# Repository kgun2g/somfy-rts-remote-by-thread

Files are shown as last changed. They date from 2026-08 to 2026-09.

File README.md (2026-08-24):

# Somfy RTS 우드 블라인드 컨트롤러 — ESP32 + CC1101

ESP32(C6 기본) + CC1101(447 MHz 2-FSK / 433 MHz OOK) + 0.42" OLED +
PCF8574 버튼/로터리로 **Somfy RTS** 블라인드(C6 8개 / H2 3개)를 제어하고,
**Matter-over-Thread**(SmartThings)로 노출하는 펌웨어.

한국 베네치아(Venetian) 블라인드의 **447 MHz 2-FSK 변종**을 정품 리모컨 IQ
녹음으로 역분석·검증해 송신한다(UP/DOWN/MY/PROG/TILT). 보드는 `boards/<board>.h`
핀맵·디스플레이·I2C 구성까지 보드별 교체 가능 — 브랜드-SoC 단위:
**3보드 모두 검증** — gnpe-c6(GNPE ESP32-C6-0.42)·xiao-c6(Seeed XIAO
ESP32-C6)·esp32-h2(ESP32-H2 SuperMini, I2C 공유).

레포: <https://github.com/kgun2g/somfy-rts-remote-by-thread>


&nbsp; 무료/오픈소스 — [MIT 라이선스](LICENSE).

## 주요 기능

- **Matter (보드별 구조)**: C6 = Bridge(Aggregator + 8× Bridged WindowCovering) →
  SmartThings 에 블라인드 8개 독립 타일 / H2 = composed(root 직속 3× WindowCovering,
  RAM 절약) → custom Edge driver 로 1카드 3블라인드. 둘 다 lift/tilt.
- **Somfy RTS 447 송신**: CC1101 2-FSK + RMT 비트뱅, 80비트(10바이트) 프레임,
  롤링코드, 블라인드별 주파수. Manchester 극성·HW/SW sync·byte 7~9·tilt 커맨드
  모두 정품 IQ 검증값. 한 누름 = **2 프레임**(첫 프레임 HW sync 12 + 재전송 6),
  **byte7 은 재전송 인덱스**(첫 프레임 `0x84`, 재전송 `196+rep*4`) — 정품·ESPSomfy 동일.
  > ★**rtl_433 이 보여주는 byte 값은 wire 바이트가 아니다.** 송신은 b[1..6]만
  > 체인 XOR 하지만 rtl_433 은 **b[1..9] 전체를 디스크램블**한다
  > (`표시 b8 = wire b8 ^ wire b7`, `표시 b9 = wire b9 ^ wire b8`).
  > 이걸 모르면 재전송 프레임의 byte7 을 "hold 코드" 로 오독한다 — 실제로 그렇게
  > 오독해 멀쩡하던 긴 누름을 깬 적이 있다. 자세한 건 `HANDOFF.md`.
- **OLED UI**: 동작 모션(UP/DOWN/STOP/TILT/PROG/ROT), 시계, 대상 블라인드 표시,
  설정 메뉴. **렌더러는 해상도로 자동 선택**(보드 무관, `BOARD_OLED_*`):
  **128×64 가로** / **64×128 세로** → 풀스크린 네이티브(고딕 폰트 + 7세그 시계),
  **그 외**(GNPE 72×40 등) → 72×40 논리 캔버스(어떤 패널에도 중앙 배치).
- **로터리 인코더**: detent 잠금 + 이탈 첫엣지 방향결정 + 2-연속표본
  디바운스(노이즈 내성). 클릭당 1동작(틸트 업/다운), 클릭=STOP/MY.
- **PCF8574 버튼**: UP/DOWN/SELECT/PROG/SETUP.
- **진동 wake**: JYX-1210-X160 진동 스위치(IO16). 절전/화면보호기 중 흔들면
  즉시 메인 화면 복귀.
- **설정 메뉴**: Cancel / Freq Edit / Time Set / Matter Pair / Thread Rst /
  FW Update (C6 6항목; **H2 는 Time Set·FW Update 제외 4항목**). SET 짧게=저장/실행, STOP=취소→메뉴.
- **기기별 고유 블라인드 ID + 블록 ALL**: 블라인드 주소를 ESP32 **eFuse 팩토리 MAC**
  (칩 고유·불변)에서 `F0+등차+ID` 형식으로 산출 → 여러 대를 만들어도 충돌 없음,
  OTA·factory reset 에도 불변. **4채널 = 1블록**, 블록마다 전용 ALL(채널 등차의 다음
  항)을 자동 산출 → ALL 명령 시 블록별 ALL 을 차례로 송신(채널↑ → 블록·ALL 자동↑).
  ([기기 고유 ID & 롤링코드 영속](#기기-고유-id--롤링코드-영속))
- **기기별 고유 커미셔닝 코드**: Matter 페어링 코드(discriminator/passcode)도 같은
  **eFuse MAC** 에서 산출(`efuse_commissionable.cpp`, custom CommissionableDataProvider)
  → 기기마다 다른 QR/PIN, `fctry` 플래시 없이 자동 고유. 여러 대 동시 페어링도 충돌 없음.
- **롤링코드 factory-reset 영속**: 롤링코드를 기본 NVS 와 분리된 전용
  `rollcode` 파티션에도 보존 → Matter factory reset(기본 NVS 삭제) 후에도
  모터가 "롤링코드 역행"으로 거부하지 않음.
- **3단계 화면보호기/절전**: 정상 → (유휴) 화면보호기 애니메이션(패널 ON)
  → 패널 OFF/절전. 버튼/진동/Matter/USB 로 즉시 복귀.
- **배터리 절전(2026-08-25 실측)** — 두 보드 모두 **light sleep 96 %대**:

  | | XIAO-C6 | ESP32-H2 |
  |---|---|---|
  | 잠 | **96.2 %** | **96.6 %** |
  | 깨어남 | **23.7 회/초** | **33.2 회/초** |
  | 깨우기 방식 | LP 코어 눌림 래치 + ULP 깨움 | PCF8574 `~INT` 레벨 트리거 |

  C6 는 깨어있는 시간 **13.4 % → 3.6 %**, 방전 **14.1 → 8.7 mV/시간**
  (700 mAh 로 **약 5일**). H2 는 **0.0 % → 96.6 %** — light sleep 이 한 번도 안 걸리던
  상태였다(`bt` PM 락).
  버튼 폴링을 늦췄는데도 **반응은 오히려 빨라졌다** — 실제 입력은 LP 코어(C6) 또는
  `~INT`(H2) 가 즉시 깨우고, 폴링은 안전망 역할만 한다.
  자세한 근거·측정법은 [`HANDOFF.md`](HANDOFF.md) 「절전 측정 현황」.
- **안전망**: 메인 루프 + 버튼 태스크 Task WDT 감시(hang 시 자동 리부트),
  RTC 메모리 crash breadcrumb(비정상 재부팅 시 부팅 직후 진단 로그).
- **펌웨어 업데이트(Matter OTA over Thread)**: 듀얼 OTA 파티션 + Matter OTA
  Requestor. Provider 가 `.ota` 이미지(버전↑) 배포 → 자동 다운로드/적용.
  설정 메뉴 `FW Update` 에서 버전·진행 확인. 절차: [`doc/OTA.md`](doc/OTA.md).

## SmartThings 제어 동작

| 조작 | RF 동작 |
|---|---|
| **Lift 슬라이더** | 방향 기반 — target>current=DOWN(닫힘), <=UP(열림). 모터가 그 방향대로 끝까지 주행(위치 피드백 없음). |
| **Tilt 슬라이더** | 정품 Tilt 커맨드(cmd nibble 0xB). delta 를 **7단계**로 환산해 N step burst(슬랫 각도). |
| **일시정지(Stop)** | Somfy MY 송신. 단, 직전 movement 500 ms 이내 auto-stop 은 무시. |
| **Open/Close** | Lift 먼저 송신, 동반 Tilt 는 companion 으로 skip(400 ms). |

> SmartThings WC UI 는 Lift/Tilt 슬라이더가 미러링돼 한쪽만 만져도 양쪽
> 명령이 온다 → 400 ms companion 가드로 먼저 들어온 쪽만 RF 송신(짧게만
> 움직이던 문제 해결). 두 슬라이더를 의도적으로 따로 조작하려면 400 ms 이상
> 간격을 둔다.

## 하드웨어 핀 배선

핀맵·디스플레이·I2C 구성의 단일 진실원천은 **`main/boards/<board>.h`**
(`BOARD_PIN_*` / `BOARD_OLED_*` / `BOARD_I2C_SHARED`). 다른 보드는
`boards/<board>.h` 추가 후 `-Board <name>` 으로 빌드.

### 지원 보드

| 보드 | SoC | 디스플레이 | I2C 버스 | PID | 배선문서 | 상태 |
|---|---|---|---|---|---|---|
| **GNPE ESP32-C6-0.42** | C6 | 내장 0.42″ 72×40 (180° 회전) | 분리(OLED HW + PCF 비트뱅) | `0x8000` | [gnpe-c6](doc/wiring/wiring_gnpe-c6.md) | ✅ 검증 |
| **Seeed XIAO ESP32-C6** | C6 | 외부 0.96″ 128×64 (정방향) | **LP_I2C→공유 자동폴백** | `0x8003` | [xiao-c6](doc/wiring/wiring_xiao-c6.md) | ✅ 검증 |
| **ESP32-H2 SuperMini** | H2 | 외부 모듈 | **공유**(OLED+PCF 한 HW I2C) | `0x8001` | [esp32-h2](doc/wiring/wiring_esp32-h2.md) | ✅ 검증 |

- **디스플레이 규격**은 보드별 `BOARD_OLED_*`(해상도/오프셋/회전/72×40 보정/주소).
  **렌더러는 해상도로 자동 선택**(`oled_ui.h` 의 `OLED_RENDER_*`) — 128×64 가로·64×128
  세로는 풀스크린 네이티브, 그 외는 72×40 논리 캔버스를 중앙 배치. 어느 보드든
  `BOARD_OLED_*` 만 바꾸면 OLED 교체 가능(코드 수정 불필요).
- **I2C 버스**: GNPE 는 OLED=HW I2C + PCF8574=비트뱅(서로 다른 핀). **H2 는
  `BOARD_I2C_SHARED=1` 로 OLED·PCF8574 가 HW I2C 한 버스 공유**. **XIAO 는 런타임 자동
  폴백**(`BOARD_I2C_LP_FALLBACK=1`): LP_I2C(뒷면 6/7) 우선 프로브 → 무응답 시 공유 HW
  I2C(22/23)로 전환 — 두 배선 모두 한 펌웨어로 지원.
- 아래 두 표는 **제품(보드)별** 핀 배치다. 단일 진실원천은 각 `boards/<board>.h`,
  상세 패드·실크 매핑은 [배선문서](doc/wiring/)를 따른다. 표기는 제품 실크 기준
  (GNPE `IOx` · XIAO 패드 `Dx`/뒷면 `MTxx` · H2 `GPx`), 괄호는 GPIO 번호.
  **★ = 기준(대표) 보드 — 상세 배선·이미지 기준(GNPE)**.

### 보드별 펌웨어 기능 차이

같은 펌웨어라도 보드 헤더(`boards/<board>.h`)의 매크로로 SoC·메모리·디스플레이에
맞춰 기능이 분기한다.

> **⚠️ H2 가 지금 형태로 구현된 근본 이유 = RAM 부족.** ESP32-H2 는 가용 RAM 이
> **~145 KB** 뿐이라 OpenThread **FTD** + Matter 스택만으로 free heap 이 거의 소진된다.
> 실측: Bridge(Aggregator+bridged) 구조로 블라인드 5개를 노출하면 `bad_alloc`/CHIP task
> 생성 실패, 3개여도 `somfy_app` 태스크가 free<5 KB 로 못 뜨고, BLE 커미셔닝 중에는 free 가
> **~2.5 KB** 까지 떨어져 PASE peak(20~30 KB)를 못 버틴다. 그래서 H2 펌웨어는 **기능을
> 빼서가 아니라 메모리가 허락하는 범위에 맞춰** 다음과 같이 축소·단순화한 형태로 구현됐다
> (C6 두 보드는 RAM 여유로 이런 제약이 전혀 없다):
>
> - **composed 구조**(Bridge → root 직속 WindowCovering): free 2.5 KB → **~72 KB** 회복
> - **채널 3개 / 블라인드 2개 안정 상한**: endpoint 가 늘수록 heap 압박 — 3개는 재커미셔닝(PASE peak) 때 부족할 수 있어 2개가 안전
> - **시각·OTA 기능 제거**: time 태스크·SNTP·OTA Requestor 를 빼 커미셔닝용 heap 확보 (`BOARD_DISABLE_TIME`/`BOARD_DISABLE_OTA`)
> - **CHIP PacketBuffer 풀 24 + CHIP task priority 15**: NimBLE mbuf·PacketBuffer 부족으로 PASE 가 실패하지 않도록 상향 (`CHIPProjectConfig.h`/sdkconfig)

위 메모리 대책의 결과로 **ESP32-H2** 는 아래가 C6 와 다르다(C6 두 보드는 공통):

| 항목 | GNPE / XIAO (C6) | **ESP32-H2** | 근거 매크로 |
|---|---|---|---|
| 블라인드 채널 | **8채널** (2블록·ALL2) | **3채널** (1블록·ALL1) | `BLIND_MAX_COUNT` |
| 설정 메뉴 | 6항목(Time Set·FW Update 포함) | **4항목**(Time/FW 제외) | `BOARD_DISABLE_TIME`·`BOARD_DISABLE_OTA` |
| 시각 동기/표시 | SetUTCTime + SNTP + 시계 | **없음**(메모리 절약) | `BOARD_DISABLE_TIME` |
| 펌웨어 OTA | Matter OTA over Thread | **없음**(메뉴에서 숨김) | `BOARD_DISABLE_OTA` |
| 페어링 화면 | PIN (72×40 은 PIN 만) | PIN + **QR**(128×64/64×128 패널) | 해상도 자동 |
| 동작 애니메이션 | 20fps 모션 | **동일 복구**(H2 분기 제거) | `oled_ui.c` |
| Matter 구조 | Bridge(Aggregator + Bridged EP) | **composed**(root 직속 WindowCovering) | `BOARD_MATTER_COMPOSED` |
| SmartThings 노출 | 블라인드별 독립 타일(스톡 드라이버) | **1카드 3블라인드**(custom Edge driver) | `smartthings-driver/` |

> 위 표의 모든 H2 차이는 별개 결정이 아니라 **하나의 원인(RAM 부족, 섹션 상단 박스)에서
> 파생**된 것이다 — 메모리가 더 컸다면 C6 와 동일했을 항목들. Vendor/Product 이름만은
> 메모리와 무관하게 전 보드 공통 **`NLB` / `Somfy RTS Thread`**(`CHIPProjectConfig.h`).

#### ESP32-H2 — SmartThings custom Edge driver 설치

H2 는 RAM 절약을 위해 **composed**(root 직속 WindowCovering EP1·EP2·EP3) 구조라, SmartThings
**스톡 `matter-window-covering` 드라이버는 다중 동일-타입 endpoint 를 1개만 매핑**해 블라인드가
하나만 보인다. `smartthings-driver/`(custom Edge driver)를 설치하면 **카드 1개 안에 블라인드 3개**
(component `main`/`blind2`/`blind3`)로 노출된다. (C6 두 보드는 Bridge 라 스톡 드라이버로 블라인드별
독립 타일 — **설치 불필요**. Apple/Google Home 은 H2 도 추가 작업 없이 3개가 보인다 — SmartThings 한정 보완.)

```bash
npm install -g @smartthings/cli                          # 0) CLI(Node 필요)
smartthings edge:drivers:package ./smartthings-driver    # 1) 패키지 → Driver Id 출력
smartthings edge:channels:create                         # 2) 배포 채널 생성 → Channel Id
smartthings edge:channels:assign                         # 3) 채널에 driver 할당 (인자=driverId)
smartthings edge:channels:enroll                         # 4) 내 허브를 채널에 등록 (인자=hubId)
smartthings edge:drivers:install                         # 5) 허브에 driver 설치 (인자=driverId)
```

> ⚠️ 명령마다 인자가 다르다 — `assign`=**driverId**, `enroll`=**hubId**, `install`=**driverId**.
> `channelId` 를 인자로 주면 `404 Missing driver`/`500` — **인자 없이** 실행해 대화형으로 고르는 게 안전.
> **적용**: 앱 → 블라인드 기기 → ⋮ → **Driver** → `Somfy Blinds 3-Shade (composed)` 선택(또는 삭제
> 후 재페어링 시 fingerprint VID `0xFFF1`/PID `0x8001` 로 자동 적용). 코드 수정 후 갱신이 안 먹으면
> `edge:drivers:uninstall`+`install` 또는 허브 재부팅(Edge 는 install 후 자동 갱신 최대 12h).
> 전체 절차·component 매핑·주의: [`smartthings-driver/README.md`](smartthings-driver/README.md).

### CC1101 SPI (제품별)

FSPI IO-MUX 네이티브 핀 우선(저속이라 GPIO-matrix 라우팅도 무방). 모듈 제조사마다
헤더 순서가 다르니 **모듈 실크스크린 라벨 기준**으로 배선할 것.

| CC1101 | ★ GNPE C6-0.42 | Seeed XIAO C6 | ESP32-H2 SuperMini |
|---|---|---|---|
| SCK  | IO6 | D8 (19)  | GP4  |
| MOSI | IO7 | D10 (18) | GP5  |
| MISO | IO2 | D9 (20)  | GP0  |
| CSN  | IO4 | D3 (21)  | GP1  |
| GDO0 | IO8 | D6 (16)  | GP10 |

> 공통: **VCC = 3.3 V / GND, 5 V 금지.** GDO0 = RMT 비동기 TX 데이터.

### 버튼/센서 (제품별)

| 신호 | ★ GNPE C6-0.42 | Seeed XIAO C6 | ESP32-H2 SuperMini |
|---|---|---|---|
| PCF8574 SDA | IO19 | D4 (22) ‡ | GP13 ‡ |
| PCF8574 SCL | IO18 | D5 (23) ‡ | GP14 ‡ |
| PCF8574 ~INT | IO17 | D2 (2) | GP11 |
| 진동 VIBE | IO16 | D0 (0) | GP2 |
| 충전 CHG_STAT | IO3 | D7 (17) † | GP12 † |
| OLED SDA | IO1 | D4 (22) ‡ | GP13 ‡ |
| OLED SCL | IO0 | D5 (23) ‡ | GP14 ‡ |

> - **‡ I2C 공유**: **H2 = OLED·PCF8574 가 HW I2C 한 버스 공유**(같은 핀, `BOARD_I2C_SHARED=1`).
>   **XIAO 는 LP_I2C(6/7) 미연결 시 이 공유 버스로 자동 폴백**. GNPE 는 PCF8574 소프트 비트뱅.
> - **XIAO PCF8574 = 자동 폴백**(`BOARD_I2C_LP_FALLBACK=1`): 부팅 시 LP_I2C(뒷면 MTCK=6/
>   MTDO=7) 우선 프로브 → 무응답 시 OLED 공유(D4/D5=GPIO22/23)로 전환(택1 불필요).
>   **† CHG_STAT**: GNPE = MCP73831 STAT(IO3, active-LOW) 직결. **XIAO·H2 는 충전 status 가
>   LED 전용**이라, 대신 **VBUS 분압(active-HIGH)=USB 감지 + BAT 분압 ADC=실측 %** 조합(A+B,
>   `BOARD_CHG_STAT_ACTIVE_HIGH`·`BOARD_HAS_BAT_ADC`)으로 충전중/만충 판별. ADC: XIAO=D1·H2=GP3.
>   ⚠ **현 시제품 H2·xiao 기판은 이 두 분압이 핀에서 swap 오배선**(BAT_ADC핀=VBUS · CHG_STAT핀=BAT).
>   CHG_STAT 핀(H2 GP12·xiao GPIO17)이 ADC·comparator 불가라 잔량 % 측정 불가 → `BOARD_BAT_SWAPPED=1`
>   로 **`USB`/`BAT`/`LOW` 상태** 표시(배선도 참고). 정상 배선으로 고치면 `0` → 실측 % 자동 복귀.
> - **PCF8574**(주소 0x20) 비트 매핑(모든 보드 공통): UP=P4 · DOWN=P5 · SEL=P6 ·
>   PROG=P7 · SETUP=P3 · 로터리 A/B/BTN = P0/P1/P2. **OLED** 주소 0x3C(SSD1306/1315).
> - **좌/우 버튼(선택)**: `BOARD_HAS_LR_BUTTONS=1` 로 **PCF8575**(16핀) 사용 시 **P10=LEFT·
>   P11=RIGHT** 추가(주소·배선 동일, 칩만 교체). 동작은 [설정 메뉴 §좌/우 버튼](#좌우-버튼-선택--pcf8575) 참고.
> - **로터리 디텐트 타입**: `BOARD_ROT_HALF_STEP` — 0=full-step(**EC11**) / 1=half-step(**EC05**,
>   rest@11·00). 펌웨어 디코더 자동 분기(half-step=그레이코드 LUT 누산). **XIAO=EC05 → 1**.
> - 진동 스위치 · CHG_STAT · PCF8574 ~INT 은 모두 light-sleep **wake 소스**.

## 빌드 & 플래시

`esp-idf`·`esp-matter`·SSD1306 SDK 와 프로젝트 경로는 **시스템 환경 변수**에서 읽는다
(`WORKSPACES_PATH`·`RTS_BLINDS_THREAD_PATH`·`IDF_PATH`·`ESP_MATTER_PATH`·`ESP_SSD1306_PATH`).
**최초 1회 등록**은 [`doc/SETUP_GUIDE.md` §5-1](doc/SETUP_GUIDE.md#5-1-시스템-환경-변수-설정-최초-1회) 참고.
프로젝트 **루트가 ESP-IDF 프로젝트**다. PowerShell 사용(Git Bash 는 MSYSTEM 충돌).

```powershell
./build.ps1 -Board esp32-c6 -Action build               # 빌드 (기본 보드)
./build.ps1 -Board esp32-c6 -Action flash -Port COM3    # 플래시
./build.ps1 -Board esp32-c6 -Action erase -Port COM3    # 전체 지움(페어링 삭제)
./build.ps1 -Board esp32-c6 -Action menuconfig          # Kconfig 편집
```

- `-Board` 기본값은 `esp32-c6`(생략 가능). 기본 보드는 기존 `build/` +
  `sdkconfig` 를 그대로 사용(역호환). 다른 보드는 `build-<board>/`,
  `sdkconfig.<board>` 별도 디렉토리/파일.
- 모든 build/flash 출력은 **`logs/<board>-<action>.log`** 로 자동 기록
  (deterministic 이름 → 덮어쓰기, 무한증식 방지). menuconfig 만 제외.
- 빌드 시작 시 보드 자산(`boards/<board>.h` + sdkconfig defaults 조합)이
  없으면 **어떤 파일이 빠졌는지** 명시하고 중단.

산출물: `build/somfy_blinds.bin` (≈1.7 MB, 앱 파티션 ~12% 여유).

### 새 보드 추가

1. `main/boards/<name>.h` — 모든 `BOARD_PIN_*`·`BOARD_OLED_*`(필요시 `BOARD_I2C_SHARED`) 정의(`gnpe-c6.h` 참고).
2. `main/boards/board_select.h` — `#elif defined(BOARD_<NAME>)` 분기 추가.
3. `build.ps1` 의 `$BoardMap` — idf target / sdkconfig defaults / esp-matter
   device 매핑 추가.
4. `sdkconfig.defaults.<name>` 작성(필요 시).

### ★ sdkconfig 주의

검증된 `sdkconfig` 가 **단일 진실원천**이다. `set-target` 으로
`sdkconfig.defaults` 에서 재생성하면 WindowCovering 클러스터 서버가
링크에서 빠져(`emberAfWindowCovering*Callback` undefined) 빌드가 깨진다.

- 평상시 `-Action build` 만 사용(기존 sdkconfig 유지).
- 부득이 `set-target` 시 스크립트가 `sdkconfig.verified.bak` 자동 백업 →
  복구: `./build.ps1 -Board <name> -Action restore-sdkconfig`.

플래시 후 재플래시가 안 되면(절전 시 USB-Serial 정지: 저전력 Matter
기기 정상 동작) 보드 **RESET** 또는 **BOOT+RESET**(다운로드 모드) 후 진행.

## 설정 메뉴 (OLED)

메인 화면에서 **SETUP 버튼 짧게** → 설정 메뉴 진입. 메뉴는 6항목 스크롤(**H2 는 4항목**)이며,
**UP/DOWN 버튼 또는 로터리 회전**으로 커서 이동, **SETUP 짧게**로 선택 항목 진입,
**STOP(로터리 클릭)** 으로 메인 복귀.

> 용어: **SETUP** = 설정 버튼(PCF8574 P3), **STOP** = 로터리 푸시 클릭,
> **틸트** = 로터리 좌/우 회전, **UP/DOWN** = 상/하 버튼.
>
> ⏻ **SETUP 15초 이상 길게 누름** = 화면 무관 **강제 재부팅**(기기 멈춤·응답불가 대비).

| 항목 | 기능 | 사용법 |
|---|---|---|
| **Cancel** | 메인 화면으로 복귀 | SETUP 짧게 = 메인 복귀 |
| **Freq Edit** | 선택된 블라인드의 송신 주파수 미세조정 (0.01 MHz 단위, 447.20~447.79) | UP / 틸트 = +, DOWN / 틸트 = − (커서 자리값) · **좌/우 = 디지트 커서**(0.1↔0.01 자리, PCF8575) · **SETUP = 저장** · STOP = 취소(변경 폐기)→메뉴 |
| **Time Set** | 날짜·시간 수동 설정 (SmartThings 미연동 시) | UP/DOWN **또는 좌/우(PCF8575)** = 편집 자리 이동(년·월·일·시·분) · 틸트 = 값 증감 · **SETUP = 저장**(시계+NVS) · STOP = 취소→메뉴 |
| **Matter Pair** | BLE 커미셔닝 윈도우 재오픈 (기존 fabric 유지, 추가 페어링) | 진입 시 자동 오픈, OLED 에 PIN 표시(128×64/64×128 패널은 좌측 PIN + 우측 **QR** 병기) · SETUP 짧게 = "준비(READY)" 확정 · STOP 짧게 = 메뉴 / 길게 = 메인 |
| **Thread Rst** | Thread 네트워크 자격증명 삭제 후 재페어링 (네트워크/허브 교체·연결 꼬임 복구용) | **SETUP 길게(2s) = 실행** · SETUP/STOP 짧게 = 취소→메뉴 · STOP 길게 = 메인 |
| **FW Update** | 펌웨어 업데이트 (Matter OTA over Thread) — 현재 버전·진행 상태 표시 | **SET = 업데이트 확인**(QueryImage) · STOP = 메뉴/메인. 상세: [`doc/OTA.md`](doc/OTA.md) |

> 🔹 **ESP32-H2 는 `Time Set`·`FW Update` 가 없는 4항목**(Cancel / Freq Edit / Matter
> Pair / Thread Rst) — 메모리 절약으로 시각·OTA 기능을 컴파일 단계에서 제외했다
> (`BOARD_DISABLE_TIME` / `BOARD_DISABLE_OTA`). [§보드별 펌웨어 기능 차이](#보드별-펌웨어-기능-차이) 참고.

### 좌/우 버튼 (선택 — PCF8575)

`BOARD_HAS_LR_BUTTONS=1` 일 때만 활성. **PCF8574(8핀) → PCF8575(16핀)** 로 칩만 교체하고
**P10=LEFT · P11=RIGHT** 를 추가한다(주소 0x20·~INT·I2C 배선 동일, read 2바이트). 동작:

| 화면 | LEFT | RIGHT |
|---|---|---|
| **메인** | 블라인드 선택 **이전** | 블라인드 선택 **다음** (SELECT 의 좌우 버전) |
| **Time Set** | 편집 자리 **이전** | 편집 자리 **다음** |
| **Freq Edit** | 디지트 커서 **0.1 자리** | 디지트 커서 **0.01 자리** (OLED 밑줄 표시 · UP/DOWN 이 그 자리값만큼 증감) |

> 좌/우 버튼 없으면(기본) 위 동작은 비활성이고 8핀 PCF8574 그대로 — `boards/<board>.h` 에서 택일.

### Freq Edit — 주파수 미세조정

블라인드별 송신 주파수를 0.01 MHz 단위로 조정한다. 표시·편집값은 **register
설정값**(기본 447.72)이며, 보드 크리스털 오차로 실제 on-air 는 다르다(아래
**RF / Somfy RTS 447** 섹션의 "register ≠ on-air" 설명 참고). 모터가 무응답이면
정품 주파수에 맞도록 여기서 미세조정. **SETUP 으로 저장**해야 NVS 에 반영되며,
저장한 값은 **재부팅 후에도 유지**된다(부팅 시 편집 범위 447.20~447.79 밖의 손상값만 기본으로 보정).

### Thread Rst — Thread 리셋

`Thread Rst` 는 **Thread 네트워크 연결을 초기화**하는 기능이다(전체 공장초기화인
`erase-flash` 보다 가벼움 — Thread/네트워크만 리셋). SETUP 길게 누르면:

1. `thread_prov_erase()` — Thread 중단 + 활성 dataset(네트워크키 등) 비움 +
   저장된 Thread 자격증명 영구 삭제.
2. BLE 커미셔닝 윈도우 재오픈 → OLED Thread 프로비저닝 화면(재페어링 대기).

**언제**: Thread 허브/Border Router 교체, Thread 연결이 꼬여 복구 안 될 때,
다른 SmartThings 계정/허브로 이전 시.

## SmartThings (Matter over Thread)

1. SmartThings 앱 → 기기 추가 → Matter → 디바이스 OLED 의 PIN/QR.
2. 커미셔닝 완료 후 블라인드 노출 — **C6** 8개 독립 타일 / **H2** 1카드 3블라인드(composed, custom Edge driver 필요).
3. 추가 페어링: 설정 메뉴 → `Matter Pair`(BLE 커미셔닝 윈도우 재개,
   기존 fabric 유지).
4. 시각: SmartThings 가 자동 동기(SetUTCTime). 미연동 시 설정 메뉴
   → `Time Set` 으로 수동 설정. (**H2 는 시각 기능 없음** — `BOARD_DISABLE_TIME`)

> 커미셔닝 중에는 OLED/버튼/RF 등 모든 부가 태스크가 정지한다(802.15.4/
> SRP/CASE 타이밍 보호 — 페어링 39-517 방지). 완료 후 자동 시작.

## RF / Somfy RTS 447 (한국 베네치아)

정품 리모컨1(addr 0xC91BF0) 의 12-bit IQ 녹음을 rtl_433 fork 로 150+ frame
디코드해 확정한 프로토콜:

- **주파수**: 기본 register 447.72 MHz → 크리스털 오차 보정 후 on-air
  ~447.678 MHz(정품과 ±3 kHz). 블라인드별 설정(설정 메뉴 → `Freq Edit`).

> #### ★ register 값(447.72) ≠ 실제 송출(447.678) — 왜?
>
> CC1101 은 **크리스털(nominal 26 MHz)** 을 기준으로 캐리어를 합성한다.
> 드라이버가 `FREQ레지스터 = 목표주파수 × 2^16 / 크리스털주파수` 로 값을
> 써넣으면, 칩은 그 값 × (실제 크리스털 / 2^16) 으로 출력한다.
>
> 문제는 **이 보드의 크리스털이 정확히 26.000000 MHz 가 아니라는 것**이다
> (제조 공차·부하 커패시터·온도로 ±수십 ppm). 측정 결과 이 모듈은
> 계산값보다 약 **-41.5 kHz**(≈-93 ppm) 낮게 송신한다. 그래서:
>
> ```
> register 447.72 입력 → 칩 합성 → 안테나 실제 출력 447.678
>                         (크리스털 오차가 -41.5 kHz 끌어내림)
> ```
>
> 정품 모터가 듣는 진짜 주파수는 **447.678** 이므로, 거기에 실제로 도달하려면
> register 에 **447.72**(= 447.678 + 0.042)를 넣어야 한다. 즉 별도 보정 코드가
> 아니라 **이 보정이 기본값 선택에 녹아 있는** 상태다.
>
> | 항목 | 의미 | 값 |
> |---|---|---|
> | register (코드→칩) | "이 주파수로 쏴" 지정값 = OLED·Freq Edit 표시값 | 447.72 |
> | on-air (안테나 출력) | 모터가 실제 받는 주파수 | ~447.678 |
> | 정품 리모컨 실측 | 목표 | 447.675~447.678 |
>
> **주의**: register 를 447.675 로 바꾸면 실제 출력이 ~447.633 으로 떨어져
> 모터가 무응답할 수 있다. OLED 상단에 보이는 주파수도 이 **register 값**이다.
> 다른 보드로 교체하면 크리스털 오차가 달라 이 보정 상수(기본 447.72)를
> 재측정·재설정해야 할 수 있다.
>
> **RF 모듈별 실측** (같은 447 대역이라도 모듈 크리스털 오차가 달라 register 권장값이 다름):
>
> | RF 모듈 | 보드 | register(설정·표시) | on-air(실측) |
> |---|---|---|---|
> | **E07-M1101D-SMA** | 테스트 보드 | 447.72 | 447.675 MHz |
> | **E07-400MM10S** | 제작 보드 | **447.70** | 447.673 MHz (실제 블라인드 인식 확인) |
>
> → 제작 보드(**E07-400MM10S**)는 `Freq Edit` 로 **447.70** 으로 맞춰야 정품 on-air(~447.67)에 도달한다.
> 새 모듈로 교체 시 SDR 등으로 on-air 를 실측해 register 를 재조정할 것.
- **변조**: 2-FSK(±2.6~2.8 kHz). (표준 433.42 MHz Somfy 는 OOK.)
- **프레임**: 80비트(10바이트). byte0=key, byte1=cmd|cks, byte2-3=rolling(BE),
  byte4-6=address(BE), byte7=0x84, byte8/9=cmd별 + calc80Checksum.
- **Manchester 극성**: '1'=LOW→HIGH, '0'=HIGH→LOW(표준 RTS/ESPSomfy 동일).
- **HW sync**: 첫 프레임 12 cycle / 반복 6 cycle, ON/OFF 2560 µs. SW sync
  4850 µs HIGH + 640 µs LOW. inter-frame gap 4000 µs.
- **주소(address)**: 24비트. 기기별로 eFuse MAC 에서 산출(아래 섹션). 주파수는
  블라인드별 NVS 저장, 롤링코드는 NVS + `rollcode` 파티션 이중 저장.
- **커맨드**: UP/DOWN/MY/PROG + **Tilt Up/Down**(cmd nibble 0xB, byte8 로 방향).
- 신규 블라인드 등록: 블라인드 선택 → `PROG` 송신(리모컨 페어링 절차).

> ESPSomfy-RTS fork(`${WORKSPACES_PATH}/ESPSomfy-RTS`)에도 동일한 447 분기를
> 반영(`modulation=0` 일 때 한국 wire-byte/timing 적용). 상세는 그 레포의
> `SOMFY_RTS_447.md`.

## 기기 고유 ID & 롤링코드 영속

여러 대를 만들어 같은 블라인드를 제어할 때 주소(=리모컨 ID)가 겹치면 안 되고,
펌웨어 업데이트·리셋에도 ID 가 바뀌면 안 된다.

### 기기별 고유 블라인드 주소 (eFuse MAC → 블록 ALL 체계)

블라인드 주소(=리모컨 ID)를 ESP32 의 **eFuse 팩토리 MAC**(칩 고유·불변)에서 FNV-1a
해시로 결정적 산출한다 (`blind_manager.c` `_derive_addresses`). 실제 Somfy 호환 리모컨
실측 규칙대로 **`F0 [중간:채널 등차] [하위:보드 ID]`** 24비트 형식이다:

```
esp_read_mac(mac, ESP_MAC_EFUSE_FACTORY);      // 칩 고유 6바이트 (불변)
h = FNV-1a(mac);  h ^= (블록+1)*0x9E3779B1;     // 블록별 salt → 블록마다 다른 base
mid  = (h>>8) % 0x27;                           // 중간바이트 = 등차 1번 최소항(0~0x26)
low  =  h     & 0xFF;                           // 하위바이트 = 보드 고유 ID
base = 0xF00000 | (mid<<8) | low;               // 채널1 주소
채널 i = base + i*0x2700;   ALL = base + 4*0x2700   // 중간바이트 +0x27 등차
```

**4채널 = 1 블록**(채널 4개 + 전용 ALL 1개). 채널이 늘면 블록(=ALL)이 자동 증가한다
(`BLIND_BLOCK_COUNT = ceil(채널수/4)`). ALL 명령은 **모든 블록의 ALL 을 차례로 송신**한다:

| 보드(채널) | 블록 | ALL | ALL 송신 |
|---|---|---|---|
| ESP32-H2 (3채널) | 1 | base+4×0x2700 | ALL 1회 |
| GNPE/XIAO C6 (8채널) | 2 | 블록0·블록1 각 ALL | ALL1, ALL2 |
| (가정) 9채널 | 3 | 블록0~2 각 ALL | ALL1, ALL2, ALL3 |

| 속성 | 보장 | 이유 |
|---|---|---|
| 기기 간 충돌 없음 | ✅ | 칩마다 다른 MAC → 다른 해시 → 다른 하위 ID |
| OTA 후 불변 | ✅ | eFuse 불변 |
| **factory reset(erase-flash) 후 불변** | ✅ | eFuse 는 flash 가 아님 + 매 부팅 enforce |
| ALL = 등차 다음 항 | ✅ | 실측: 채널 4개 뒤 ALL = base+4×0x2700(중간바이트 +0x27 규칙) |

> ⚠️ `esp_efuse_mac_get_default()` 는 C6 에서 EUI-64 형태(중간 `FF:FE` 패딩)를 줘
> 고유 바이트가 거의 없다 → 반드시 `ESP_MAC_EFUSE_FACTORY` 를 쓸 것.
> ※ **ALL 은 PROG 등록 절차가 없다** — 모터는 채널 주소만 PROG 로 받고 ALL 은 내부
> 인식한다. 펌웨어는 ALL 주소를 등차로 산출해 **송신만** 한다. 주소를 바꾼 기기는
> 채널마다 모터에 **PROG 재등록** 필요(새 주소 = 새 리모컨 ID).

### 롤링코드 factory-reset 영속 (채널 + 블록 ALL)

롤링코드는 매 송신마다 증가하고, 모터는 직전보다 작은 롤링코드를 replay 로
거부한다. 기본 NVS 에만 두면 Matter factory reset(기본 NVS 전체 삭제) 시
START 로 리셋 → 모터 무응답. 그래서 **전용 `rollcode` NVS 파티션**(partitions.csv,
0x3E6000/16KB)에 **채널과 블록 ALL 롤링코드를 모두** 보존하고(`rollcode_blob_t`
= `rolling[채널]` + `all_rolling[블록]`), 부팅 시 **더 큰 값을 채택**(역행 방지)한다.
특히 **ALL 은 PROG 재등록 절차가 없어** 롤링코드가 한 번 어긋나면 복구가 불가능하므로
ALL 롤링코드의 영속이 채널 못지않게 중요하다.

| 이벤트 | 롤링코드(채널 + 블록 ALL) |
|---|---|
| 일반 송신 | NVS + `rollcode` 파티션 동시 갱신 |
| OTA | 둘 다 보존 |
| **Matter factory reset**(기본 NVS 삭제) | `rollcode` 파티션 보존 → 채널·ALL 모두 복원 ✅ |
| 전체 `erase-flash` | 모두 삭제 → 재-PROG 필요(개발자 행위) |

### 기기별 고유 커미셔닝 코드 (eFuse MAC → discriminator/passcode)

Matter 페어링 코드(discriminator 12bit + passcode + Spake2p verifier)도 블라인드 주소와
같은 **eFuse 팩토리 MAC** 에서 결정적 산출한다(`efuse_commissionable.cpp`, custom
`CommissionableDataProvider`). `fctry`(factory_nvs_gen.py) 플래시 없이도 **기기마다 다른
페어링 코드**를 가져, 여러 대를 만들어 동시에 페어링해도 BLE discriminator 충돌이 없다.

```
mac = eFuse FACTORY MAC;   h = FNV-1a(mac) ^ "COMM" salt
discriminator = (h ^ h>>12 ^ h>>23) & 0xFFF   // 비트 폴딩 → short(상위 4bit)도 분산
passcode      = (h % 99999998) + 1            // 유효 PIN 보정
verifier      = Spake2pVerifier.Generate(iter=1000, salt(eFuse), passcode)  // PASE
```

| 속성 | 보장 |
|---|---|
| 기기 간 코드 충돌 없음 | ✅ eFuse 고유 — 실측 gnpe `3327`/12 · xiao `4032`/15 · h2 `2687`/10 (long·short 모두 다름) |
| fctry 플래시 불필요 | ✅ 펌웨어가 부팅 시 자동 산출 |
| DAC(인증서)는 별개 유지 | ✅ commissionable provider 만 교체(DAC provider 무관) |

> `sdkconfig`: **`CONFIG_CUSTOM_COMMISSIONABLE_DATA_PROVIDER=y`** (C6·H2 적용). 미설정 보드는
> 기존 경로(EXAMPLE 기본 `3840`/`20202021`). discriminator 12bit(4096)·short 4bit(16) 공간이라
> 수십 대 규모면 충돌 가능(생일 문제) — 그땐 `factory_nvs_gen.py` 로 fctry 고유성 부여.

## OLED 구동 방식 & 화면 정책 (2026-08-11 갱신)

### 비트뱅 I2C (`BOARD_OLED_BITBANG`, xiao-c6 = 1)

xiao-c6(h4)에서 **ESP32 하드웨어 I2C0 페리페럴이 "bus busy" 로 고착**되는 현상이 재현됐다.
라인은 idle(1/1)인데 `i2c.master: clear bus failed` / `reset hardware failed` 가 뜨고 버스를
지웠다 다시 만들어도 풀리지 않는다. 같은 순간 **순수 GPIO 비트뱅은 정상 ACK** 를 받는다.

→ OLED 전송을 비트뱅으로 옮겨 페리페럴을 통째로 우회한다.

- `_bbo_write()` : GPIO **레지스터 직접 접근**(`GPIO_OUT_W1TS/W1TC`, `GPIO_IN`). HAL 호출
  (`gpio_set_direction`)은 비용이 크고 불규칙해 400 kHz 에서 파형이 깨진다(화면에 랜덤 점).
- 핀은 `GPIO_MODE_INPUT_OUTPUT_OD` 로 **한 번만** 설정하고 이후 출력 레지스터만 토글한다.
  `OUTPUT_OD` 로 하면 입력 버퍼가 꺼져 읽기가 항상 0 이 되므로 반드시 `INPUT_OUTPUT_OD`.
- 속도 `BBO_HALF_US` (1 ≈ 400 kHz). 점/깨짐이 보이면 2~3 으로 올릴 것.
- HW I2C 버스를 **아예 만들지 않으므로**, PCF8574 를 OLED 와 공유 HW I2C 로 쓰는 보드
  (`BOARD_I2C_SHARED` 경로, 예: esp32-h2)는 이 옵션과 함께 쓰지 말 것.
- **이식성 주의**: 비트뱅 계측 전역(`g_bbo_tx_cnt` 등)은 `#if BOARD_OLED_BITBANG` **밖**에
  선언해야 한다. 가드 안에 두면 `BOARD_OLED_BITBANG=0` 보드(H2)에서 링크 에러가 난다.

### dirty-page 전송 감축

화면 전체를 매번 재전송하면 초당 약 450 건의 I2C 트랜잭션이 발생한다(전송 1건 = 고착 기회).
마지막으로 성공 전송한 페이지를 `s_shadow` 에 보관하고 **내용이 바뀐 페이지만** 보낸다.
전송 실패 시 shadow 를 갱신하지 않아 다음 주기에 자동 재시도되고, 검출 실패/재검출 시에는
무효화해 전량 재전송한다. 실측: 전송 **75 % 감축**, 페이지 **86 % 건너뜀**.

### 화면 정책 — 화면보호기 없음

- 화면보호기(중간 애니메이션)는 **코드째 삭제**됐다. 유휴 시간이 지나면 곧바로 패널 OFF.
- 꺼지는 시간은 **전원에 따라 다르다**(`main/somfy_config.h`):

  | 전원 | 매크로 | 기본값 | 이유 |
  |---|---|---|---|
  | USB | `CFG_SCREEN_OFF_USB_SEC` | **300초(5분)** | 전원이 무제한 — 작업 중 자꾸 꺼지면 불편 |
  | 배터리 | `CFG_SCREEN_OFF_SEC` | **10초** | 화면이 소비의 큰 몫 |

  보드별로 바꾸려면 `boards/<board>.h` 에서 먼저 정의하면 된다.
- 복귀: **버튼 또는 진동**. 스택이 자동 진입하는 상태(PAIRING/THREAD_PROV/CHARGING)는
  화면 유지 조건에서 제외했다 — 포함하면 유휴 타이머가 계속 리셋돼 화면이 영영 안 꺼진다.

### 채널변경 잠금 (`CFG_CH_LOCK_MS`, 기본 700 ms)

상/하 등을 **동시에** 누를 때 좌/우가 스쳐 채널이 바뀌는 것을 막는다. 아래 중 하나라도
해당하면 SELECT·좌·우를 무시한다.

1. RF 발생 버튼(상·하·정지(로터리)·PROG)이 눌려 있는 동안
2. 동작 애니메이션이 재생되는 동안 (`OLED_STATE_ACTION`)
3. 마지막 RF 버튼 눌림 후 `CFG_CH_LOCK_MS` 이내 (동시 누름의 "텀" 대응)

### I2C 직렬화 — 락은 `_bbo_write()` 한 곳에 (2026-08-11)

**모든 비트뱅 전송은 `_bbo_write()` 안에서 재귀 뮤텍스로 보호된다.** 락을 여기 한 곳에만
두면 호출 지점이 늘어도 자동으로 보호된다.

왜 이렇게 바뀌었나 — 전에는 `_fb_flush` 만 락을 잡아 아래 두 경로가 **무방비**였다.

| 무방비였던 경로 | 호출자 | 빈도 |
|---|---|---|
| `_oled_send_cmds()` ← `oled_ui_set_display_on()` | somfy_app | 화면 자동 OFF/ON **10초마다** |
| `_bbo_probe()` ← `_oled_try_detect()` | flush 의 early-return 경로(락 잡기 **전**) | 미검출 시 5초마다 |

태스크 우선순위가 **`btn_handler` 10 > `somfy_app` 4 > `oled_ui` 3** 이라 somfy_app 이
oled_ui 를 **선점**한다. 비트뱅은 CPU 가 곧 클럭이므로, 선점당한 전송은 SCL/SDA 가 중간
상태로 수백 µs 멈춰 SSD1306 상태머신이 고착된다(한 번 고착되면 저절로 안 풀리는 래치).

- **재귀 뮤텍스여야 한다.** `_fb_flush` 가 바깥 락을 쥔 채 `_bbo_write` 를 부르므로,
  일반 뮤텍스면 자기 자신을 기다려 **즉시 데드락**(화면 영구 정지)이다.
  `xSemaphoreCreateRecursiveMutex` + `xSemaphoreTakeRecursive`/`GiveRecursive` 를 쓸 것.
- 뮤텍스는 `oled_ui_init()` **맨 앞**에서 만든다. 늦게 만들면 그 사이 호출이
  `s_i2c_mutex == NULL` 을 만나 무보호로 통과한다.
- 락 획득 타임아웃(200 ms)이 나면 **그냥 전송한다**. 락은 겹침 방지용이지 전송의
  전제조건이 아니며, 화면을 영구히 멈추는 것보다 한 프레임 깨지는 편이 낫다.
  발생 횟수는 `[OLEDMON]` 의 `lockTO` 로 관찰한다(정상 = 0).

검증: `sim/tools/adc_oled_mutex_sim.py` (8시드 × 10분) — 수정 전 **6/8회 고착(최빠른 80초)**,
수정 후 손상 0 / 고착 0 / 배터리 측정 952/952.

**실기 장시간(2026-08-11, COM7)**: 콘솔 `cyc` 로 화면을 계속 갱신시킨 100 % 부하 +
ADC 5초 주기 병행으로 **4시간 45분 / 전송 257,562건 / 실패 0 / lockTO 0**,
`present` 284개 샘플 전부 1, 패닉·재부팅·워치독·버스복구 0건, free heap Δ-80 B.

### 충전률 측정 (재활성됨, 2026-08-11)

`TEMP_NO_CHARGE = 0`. 위 직렬화 수정으로 되살렸다.

- **측정 주기 5초 · 표본 8회는 그대로 둘 것.** 줄이면 `_nobat_track` 의
  "5분 창 / 반쪽당 30표본" 노이즈 상쇄 가정이 깨져 **배터리 미연결 오판**이 생긴다.
  (30초 주기면 반쪽당 5표본 → 노이즈가 판정 문턱 4 mV 에 근접한다.)
- 문제가 재발하면 `TEMP_NO_CHARGE` 를 1 로 되돌리고 `[OLEDMON]` 의 실패·`lockTO` 를 볼 것.

### 배터리 미연결 판정과 "78%" (2026-08-11)

배터리를 빼도 충전 IC(MCP73831)가 BAT+ 를 무부하로 **약 3,970 mV** 로 띄운다.
이 값은 OCV-SoC 곡선상 정확히 **78 %** 라, 예전에는 "배터리 없는데 78 %" 로 보였다.
**전압만으로는 실제 배터리 78 % 와 구분할 수 없다.**

유일한 단서는 **전압이 오르는가**다(무배터리 float = 안 오름 / 충전 중인 셀 = 오름).
`_nobat_track()` 이 5분 창의 전반·후반 평균을 비교해 판정한다.

- **첫 판정 전에는 % 를 표시하지 않는다** (`BAT_PCT_UNKNOWN` → 화면에 `--%`).
  단 **애매할 때만** 숨긴다: float 창(3940~4010 mV) **밖**이면 충전 IC 가 그 값을
  만들 수 없어 배터리 존재가 전압만으로 확정되므로 **대기 없이 즉시** % 를 보여준다.
  USB 가 없을 때(=배터리로 구동 중)도 배터리가 있는 게 자명하므로 즉시 표시한다.
- **창(5분)을 줄이면 안 된다.** 충전 상승률이 ≈9.3 mV/5분 이라 창이 짧으면
  전반/후반 평균차가 판정 문턱(4 mV)에 못 미쳐 **진짜 충전 중인 배터리를 "미연결"로
  오판**해 0 % 로 표시한다. 3분 창 = 2.8 mV 로 이미 위험하다.
- 실기 로그: `[BAT] 배터리 판정: 미연결 → 0% 표시 — 전반3970mV(n30) 후반3969mV(n30)
  상승-1mV (창O, 안오름O, USB=1)` 가 부팅 **5분 23초**에 나온다.
- 검증: `sim/tools/bat_pct_display_sim.py` (4개 시나리오 + 창 단축 위험 표)

### 배터리 % 표시 평활 (2026-08-11)

배터리 구동에서는 BLE 광고·RF 송신 순간 **실제로** 전압이 떨어진다. 5초 주기 측정이
그 순간에 걸리면 값이 크게 낮게 찍히고, OCV 곡선상 이 구간은 **1 % ≈ 10 mV** 라
100 mV 만 흔들려도 10 %p 가 움직인다(실측: 81→82→**74**→84→81 %).

`_read_bat_mv()` 의 8회 평균은 수십 µs 안에 끝나 **같은 순간을 8번 재는 것**이라
ADC 노이즈만 줄일 뿐 부하 변동은 못 거른다. 그래서 **표시 경로에만** 후처리를 넣었다:

1. **중앙값 5주기**(`_bat_smooth_mv`) — 송신 순간에 걸린 점을 통째로 버린다
2. **EMA(α=1/4)** — 남은 흔들림을 시간축으로 누른다

`_nobat_track` 에는 **원본 값**을 준다 — 그쪽은 5분 창 30표본 통계라 평활하면
"전압이 오르는가" 판정 가정이 깨진다. 측정 주기·표본 수도 그대로 둔다.

★**EMA 는 1/16 mV 단위로 누적**한다. C 의 정수 나눗셈은 0 쪽으로 절단하므로 1 mV
단위로 쓰면 차이가 1~3 mV 일 때 몫이 0 이 되어 **EMA 가 고착**된다.

검증(`sim/tools/bat_pct_smooth_sim.py`): 진폭 19→9 %p, 주기간 변동 4.09→0.38 %p,
송신 강하 이상치 미노출, 방전 추종 지연 2 %p 이내.

### 배터리 단독 부팅 (USB 없이) — 2026-08-11

**증상**: USB 를 빼고 배터리만 연결하면 부팅 화면에서 멈추고 40초~1분마다 재부팅.

**원인**: `esp_matter::console::init()` 이 CHIP shell 을 **우선순위 5** 태스크로 띄운다
(`somfy_app`=4, `oled_ui`=3 보다 높다). 이 태스크가 프롬프트를 출력하는데, 보조 콘솔이
USB-Serial-JTAG 이라 `esp_rom_usb_serial_putc` 가 줄바꿈마다
`usb_serial_device_tx_flush()` 로 **호스트를 기다린다**. USB 가 없으면 이 대기가 길어지고
prio 5 가 아래 태스크를 굶겨 부팅이 끝나지 않는다.

**수정**: **VBUS 가 실제로 있을 때만** CHIP shell 을 시작한다(`app_main.cpp`
`_usb_vbus_present()` — GPIO17 VBUS 분압). 콘솔은 개발용이고 `tx`/`sel`/`cyc`/`bd` 도
USB 전용이라 배터리 단독 동작에는 필요 없다.

> `usb_serial_jtag_is_connected()` 를 쓰지 않은 이유: SOF 패킷 기반이라 부팅 ~1초
> 시점엔 열거가 안 끝나 false 가 나올 수 있고, 그러면 **USB 개발 중에도 콘솔이 사라진다**.

**진단 방법 — `boot_diag`** (`main/boot_diag.c`): USB 를 꽂는 순간 증상이 사라져 시리얼
로그를 볼 수 없으므로, 전원이 끊겨도 남는 **NVS 부팅 단계 기록**을 만들었다(RTC RAM 은
배터리를 빼면 지워져 못 쓴다). app_main 경로와 somfy_app 경로를 **따로** 세고, 실패한
부팅은 별도 키에 **영구 보관**한다(정상 부팅이 덮어쓰지 않게).

- 콘솔 `bd` — 언제든 조회 / `bd clear` — 보관 기록 삭제
- 끄려면 `BOOT_DIAG_ENABLE 0`(부팅당 NVS 쓰기 ~17회)

### 진단 로그

- `[OLEDMON]` (60초 주기) — 가동시간 · 전송/실패 · 페이지 보냄/건너뜀 · **`lockTO`** · `present` · free heap
- `[BBFAIL]` — 비트뱅 전송 실패(20회마다 1줄)
- ★**로그 인코딩은 캡처 경로마다 다르다.** pyserial 직접 캡처 = **UTF-8**,
  빌드 로그(`logs/*.log`) = **CP949**. 틀리게 디코드하면 한글 에러가 0건으로 오독된다.
  `try utf-8 → except cp949` 로 판별할 것.
- ★**"실패 0"은 정상의 증거가 아니다.** OLED 미검출이면 flush 를 건너뛰어 전송도 에러도
  안 생긴다. **`present=1` 과 전송 카운터 증가를 함께** 봐야 한다.

### 알려진 미해결 / 임시 상태

- **진동센서 오검출** — 핀이 고정 HIGH 인데 ISR 이 계속 발생해 화면이 저절로 켜지는 사례.
  `[VIBE-stat] 진동=1 HIGH=300/300` 로 확인. HW 로는 VIBE 핀·VS1 배선 점검 필요.
- **ESP32-H2 메모리** — 블라인드 3개면 free heap 이 5 KB 미만까지 떨어진다(C6 는 171 KB).
  H2 는 `BLIND_MAX_COUNT` 를 2 이하로 둘 것.
  ※**2026-08-24 이후 사정이 크게 달라졌다.** `CONFIG_USE_BLE_ONLY_FOR_COMMISSIONING=y`
  로 등록 후 BLE 를 내리자 **free 11.3 KB → 40.5 KB (+29.2 KB)**. 여기에 2026-08-22
  태스크 통합(`time_update`·`time_persist` → 메인 루프)으로 5 KB 이상을 더 회수했다.
  ※단 벽은 **총량이 아니라 연속 블록**이다 — free 5.9 KB 가 남았는데도 최대 연속
  블록이 2,112 B 라 NOC 인증서 검증이 실패한 적이 있다(2026-08-19).
  ※대가: 이미 등록된 기기는 **BLE 광고를 하지 않는다.** 재페어링은 공장초기화 후.

## 안전 / 진단

- **Task WDT**: 메인 루프 + 버튼 태스크가 5 s 이상 멈추면 자동 panic→리부트.
- **Crash breadcrumb(RTC 메모리)**: 비정상 재부팅 시 부팅 직후 직전 tick
  카운터/타임스탬프/상태(screensaver·sleep·setup)를 ★ 로그로 덤프 →
  어느 태스크가 어디서 멈췄는지 추정.
- **화면보호기 stuck 복구**: 플래그가 false 여도 OLED state 가 SCREENSAVER 면
  버튼/진동 입력 시 강제 재해제.

시리얼 캡처(진단용):
```powershell
python read_serial.py COM3 115200 > logs/serial_latest.log
```

### 시리얼 콘솔 (진단 / 자동 테스트)

USB Serial JTAG 콘솔로 **버튼 없이** RF 송신·블라인드 선택·순환·주파수 설정·재부팅을
무인 제어한다 — PC 가 COM 포트로 기기를 직접 구동해 RF 를 쏘고 SDR(`somfy_cli`)로
캡처·분석하는 자동 루프에 쓴다(`read_serial.py` 패턴, `sim/tools/`).

| 명령 | 동작 |
|---|---|
| `tx up\|down\|updown\|myup\|mydown\|my\|prog [hold_ms]` | Somfy RF 송신(session-gate 우회 → combo 직접 지정). 실측 `tx up`=cmd2 · `tx updown`=cmd6 |
| `sel <0..N \| N=ALL>` | 블라인드 선택 (N = `BLIND_MAX_COUNT`; H2 `3`·C6 `8` = ALL) |
| `cyc <-1 \| 1>` | 블라인드 선택 순환(`_blind_cycle`) — PCF8575 LEFT/RIGHT 의 콘솔 버전 |
| `freq [idx mhz]` | 주파수 조회 / 설정(+NVS 저장, 447.20~447.79 클램프) |
| `reboot` | `esp_restart` 재부팅 |
| `bd` / `bl` / `vl` | 부팅 진단 / 배터리 방전 기록 / 진동센서 기록 (NVS) |
| **`tmr`** | **등록된 `esp_timer` 덤프** — 깨어남 출처 추적. 이 한 줄이 "깨어남의 78 %" 범인(쓰지도 않는 `iot_button` 20 ms 타이머)을 찾아냈다 |
| **`pm`** | **`esp_pm_dump_locks`** — 누가 light sleep 을 막는지 이름으로 나온다(`CONFIG_PM_PROFILING=y` 면 보유 시간 %까지) |
| `rt` | 태스크별 CPU 점유(`CONFIG_FREERTOS_GENERATE_RUN_TIME_STATS` 필요) |

### 절전 진단 — 추정하지 말고 찍을 것

절전 원인 추적에서 가설이 **세 번 연속 틀렸고**(LP 코어 정지 / PCF 지터 /
Matter 내부 타이머), `esp_timer_dump()` 한 줄이 그걸 끝냈다. 순서는 이렇게 한다:

1. **`tmr`** — 12~20 ms 같은 짧은 주기 타이머가 있으면 그게 천장이다.
   *신호*: 수면 길이가 **특정 값을 절대 안 넘으면** 그 주기의 타이머가 있다는 뜻.
2. **`pm`** — `Active=1` 로 오래 잡힌 락이 있으면 light sleep 은 시도조차 못 한다
   (`light_sleep_counts:0`). `batlog` 의 `pm=3` 은 "설정이 허용됐다"는 뜻일 뿐
   **자고 있다는 증거가 아니다.**
3. 배터리 구간은 USB 콘솔이 죽으므로 **NVS 로** 받는다 —
   `sim/tools/batlog_decode.py`(수면 길이 히스토그램·깨어남 원인·태스크별 반복),
   `sim/tools/pmdump_decode.py`(PM 락 보유자),
   `sim/tools/bat_current_estimate.py`(방전 → 실효 전류).
4. **비교는 같은 출발·도착 전압 구간으로.** OCV 기울기가 구간마다 2.3 배 다르다
   (3850~3950 = 5.0 mV/%p vs 4080~4150 = 11.7 mV/%p). 어기면 수면 전류가
   음수로 나오는 식의 헛계산이 된다.

> ⚠️ **멀티미터 직렬 전류 측정은 이 기판에서 불가**(배터리 선을 끊을 수 없다).
> 배터리 +/− 에 **전류계 모드로 직결하면 셀 단락** — 절대 금지. 전압만 잰다.

> ★ **USB Serial JTAG 를 primary 콘솔**로 둬야 명령 입력이 먹는다(UART default 면 COM 에
> stdin 이 없어 write 가 hang). 또 pyserial 로 포트를 **여러 번 여닫으면 DTR 토글로 리셋**되니
> 한 세션(단일 open) 안에서 연속 전송할 것.

## 프로젝트 구조

```
somfy-blinds-things-by-claude/        ← ESP-IDF 프로젝트 루트
├─ CMakeLists.txt   project(somfy_blinds)
├─ build.ps1        보드별 빌드/플래시/ota-image(-Board), logs/ 자동 기록
├─ sdkconfig        검증된 설정(단일 진실원천)  + sdkconfig.verified.bak
├─ sdkconfig.defaults, .c6_thread, .h2_thread, .xiao_c6
├─ partitions.csv   ota_0/ota_1(듀얼 OTA) + rollcode(롤링코드 영속) + fctry
├─ logs/            빌드/플래시/시리얼 로그(<board>-<action>.log) — git ignore
├─ dist/            보드별 Matter OTA 이미지(.ota) — git ignore
├─ main/
│   ├─ boards/             브랜드-SoC 단위 핀맵 (OTA PID 도 보드별 분리)
│   │   ├─ board_select.h   -DBOARD_<NAME> → 핀맵 분기 + 필수 매크로 검증
│   │   ├─ gnpe-c6.h        GNPE ESP32-C6-0.42 (검증, PID 0x8000)
│   │   ├─ xiao-c6.h        Seeed XIAO ESP32-C6 (검증, PID 0x8003)
│   │   ├─ esp32-c6.h       구 키 → gnpe-c6.h 별칭(역호환)
│   │   └─ esp32-h2.h       ESP32-H2 SuperMini(Thread, 검증, I2C 공유)
│   ├─ app_main.cpp        Matter 코어/노드/엔드포인트/WC delegate/OpenThread
│   ├─ app_driver.cpp      Matter attribute/identify 글루
│   ├─ matter_blinds_shim.cpp  matter_blinds_* C API (상태조회/재커미셔닝)
│   ├─ somfy_app.c         OLED/버튼/메뉴/시계/절전/안전망 애플리케이션
│   ├─ cc1101.c/.h         CC1101 드라이버 (핀은 boards/<board>.h 에서 파생)
│   ├─ somfy_rts.c/.h      Somfy RTS 447 프로토콜(프레임/타이밍/tilt step)
│   ├─ blind_manager.c/.h  블라인드 상태/NVS
│   ├─ oled_ui.c/.h        OLED UI/모션
│   ├─ button_handler.c/.h PCF8574 버튼 + 로터리 + 진동 ISR
│   ├─ thread_provision.c/.h
│   ├─ somfy_config.h      핀(BOARD_PIN_* 참조)/타임존/주파수 등 설정
│   └─ gen_build_epoch.cmake  빌드시각 헤더 생성
├─ doc/             문서(README 제외 전부) — 아래 "문서" 참고
│   ├─ SETUP_GUIDE.md   배선/빌드/플래시/페어링 단계별 가이드
│   ├─ CHECKLIST.md     기능 체크리스트 + 메모리/파티션 현황
│   ├─ OTA.md           Matter OTA(over Thread) 워크플로
│   ├─ CLEANUP_v3.5.md  정리 노트
│   ├─ architecture.html 아키텍처 다이어그램
│   ├─ wiring/          보드별 배선도 (gnpe-c6 / xiao-c6 / esp32-h2)
│   └─ CC1101/ esp32/ parts/  데이터시트·핀맵 이미지·부품 자료
└─ test/            가상/온에어/디코더 테스트 하네스(build_test.ps1)
```

## 문서

루트에는 본 `README.md` 만 두고, 나머지 문서는 모두 [`doc/`](doc/) 아래에 있다.

| 문서 | 내용 |
|---|---|
| [`doc/SETUP_GUIDE.md`](doc/SETUP_GUIDE.md) | 배선·빌드·플래시·Matter 페어링·트러블슈팅 단계별 가이드 |
| [`doc/CHECKLIST.md`](doc/CHECKLIST.md) | 구현 기능 체크리스트, 메모리/파티션 현황 |
| [`doc/OTA.md`](doc/OTA.md) | Matter OTA(over Thread) 이미지 생성·배포·보드별 PID |
| [`smartthings-driver/README.md`](smartthings-driver/README.md) | **ESP32-H2(composed) 전용** SmartThings custom Edge driver — 1카드 3블라인드 노출 + CLI 배포 절차 |
| [`doc/wiring/`](doc/wiring/) | **보드별 배선도** — [gnpe-c6](doc/wiring/wiring_gnpe-c6.md) · [xiao-c6](doc/wiring/wiring_xiao-c6.md) · [esp32-h2](doc/wiring/wiring_esp32-h2.md) |
| [`doc/architecture.html`](doc/architecture.html) | 아키텍처 다이어그램 |

> `CLAUDE.md`(루트) 는 에디터 툴 지침이라 문서가 아니며, Claude Code 가 루트에서
> 읽어야 하므로 이동하지 않는다.

## 외부 의존성 (SDK, 별도 위치 유지)

대형 SDK 는 저장소에 포함하지 않고 환경변수 경로에서 참조한다. **검증에 사용한 정확한 리비전**:

| 의존성 | 버전 / 리비전 | 경로 |
|---|---|---|
| **ESP-IDF** | **v5.4.1** (tag · 커밋 `4c2820d377`) | `${WORKSPACES_PATH}/esp-idf` |
| **esp-matter** | 커밋 `7706cfbd` (main · 2026-03-31 · 태그 없음) | `${WORKSPACES_PATH}/esp-matter` |
| **esp-idf-ssd1306** | 커밋 `554df45` (master · 2026-02-20) | `${WORKSPACES_PATH}/esp-idf-ssd1306` |

> esp-matter 는 connectedhomeip(Matter 코어)를 submodule 로 동봉 — esp-matter 리비전에 고정된다.

### 관리 컴포넌트 (IDF Component Manager · 자동 다운로드)

`main/idf_component.yml` 이 직접 선언하고 나머지는 esp-matter 가 끌어온다. 잠금은
`dependencies.lock`(매니페스트 `2.0.0` · target `esp32c6`):

| 컴포넌트 | 버전 | 용도 |
|---|---|---|
| `espressif/qrcode` | **0.2.0** | OLED 페어링 QR 인코더 (직접 선언 `*` → 잠금 0.2.0) |
| `espressif/cmake_utilities` | 1.1.1 (`^1`) | 빌드 유틸 (직접 선언) |
| ~~`espressif/button`~~ | ~~4.1.6~~ | **2026-08-24 제거** — 20 ms 주기 `esp_timer` 를 상시 돌려 깨어남의 78 %를 차지했다. 공장초기화 BOOT 버튼 하나에만 쓰였고(사용 안 함), 실제 조작 버튼은 전부 PCF8575 → `button_handler` 가 처리한다 |
| `espressif/mdns` | 1.11.1 | Matter mDNS / SRP |
| `espressif/esp_secure_cert_mgr` | 2.9.2 | DAC 인증서 파티션 |
| `espressif/esp_delta_ota` · `esp_encrypted_img` | 1.1.4 · 2.3.0 | OTA 델타 · 암호화 |

## 참조 프로젝트

본 펌웨어가 의존하거나 참조한 프로젝트와 git 주소.

| 프로젝트 | 버전 / 리비전 | 용도 | Git |
|---|---|---|---|
| **이 프로젝트** | v3.x (Matter over Thread) | Somfy RTS · Matter-over-Thread 펌웨어 | <https://github.com/kgun2g/somfy-rts-remote-by-thread> |
| **ESP-IDF** | **v5.4.1** | ESP32 빌드 SDK/RTOS (Apache-2.0) | <https://github.com/espressif/esp-idf> |
| **esp-matter** | `7706cfbd` (main) | Matter SDK (Apache-2.0) | <https://github.com/espressif/esp-matter> |
| **connectedhomeip** | esp-matter 동봉 submodule | Matter 코어 SDK (esp-matter 가 래핑, Apache-2.0) | <https://github.com/project-chip/connectedhomeip> |
| **esp-idf-ssd1306** | `554df45` (master) | SSD1306/SSD1315 OLED 컴포넌트 (MIT) | <https://github.com/nopnop2002/esp-idf-ssd1306> |
| **ESPSomfy-RTS** | fork (447 분기 · `modulation==0`) | Somfy RTS 프로토콜 참조 구현 (447 분기 작업의 기준) | <https://github.com/kgun2g/ESPSomfy-RTS> |
| **rtl_433** | fork (`somfy-RTS-447` device) | RF 디코딩·검증(송신 프레임 역검증) | <https://github.com/kgun2g/rtl_433> |

> Somfy RTS 447 분기는 본 저장소와 더불어 `ESPSomfy-RTS`·`rtl_433` 의 로컬 fork(`modulation==0`
> / `somfy-RTS-447`)에도 반영했다. 각 의존성은 자체 라이선스(대부분 Apache-2.0/MIT)를 따른다.

| 역할 | Fork (kgun2g) | Upstream |
|---|---|---|
| ESPSomfy-RTS (447 MHz 지원 추가) | https://github.com/kgun2g/ESPSomfy-RTS | https://github.com/rstrouse/ESPSomfy-RTS |
| rtl_433 (447 MHz 지원 추가) | https://github.com/kgun2g/rtl_433 | https://github.com/merbanan/rtl_433 |
| SDR# plugin (447 MHz 지원 추가, SDR# 측 UI) | https://github.com/kgun2g/plugin-Rtl433-for-SdrSharp | https://github.com/marco402/plugin-Rtl433-for-SdrSharp |
| SDR# plugin DLL (447 MHz 지원 추가) | https://github.com/kgun2g/Rtl_433_dll-for-plugin-SdrSharp | https://github.com/marco402/Rtl_433_dll-for-plugin-SdrSharp |
| GraphLibSpecific (.NET 9 재빌드) | https://github.com/kgun2g/GraphLibSpecific | https://github.com/marco402/GraphLibSpecific |

## 라이선스

[MIT 라이선스](LICENSE) — 자유롭게 사용·수정·배포 가능(무료/오픈소스). © 2026 kgun2g.
저작권 고지와 라이선스 전문을 포함하면 된다. 외부 의존성(ESP-IDF·esp-matter 등)은
각 프로젝트의 라이선스를 따른다.

## 참고

- 핀맵·빌드·버전의 현행 기준은 본 README 와 `main/boards/<board>.h` 다.
  다른 문서와 상충 시 본 문서 우선.

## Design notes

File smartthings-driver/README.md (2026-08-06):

# Somfy Blinds 3-Shade — SmartThings custom Edge driver

composed Matter 기기(root EP0 + WindowCovering EP1·EP2·EP3)를 **SmartThings 카드 1개 안에 블라인드 3개
컨트롤**(component `main` / `blind2` / `blind3`)로 노출한다. 스톡 `matter-window-covering` driver 가
composed 의 다중 동일-타입 endpoint 를 1개만 매핑하는 한계를 우회한다.

> 펌웨어는 이미 WindowCovering endpoint 3개를 정상 노출한다(Apple/Google Home 은 추가 작업 없이 3개가
> 보인다). 이 driver 는 **SmartThings 쪽 매핑**만 보완한다.

## 구조
```
smartthings-driver/
  config.yml                 # driver 메타(name, packageKey, matter 권한)
  fingerprints.yml           # VID 0xFFF1 / PID 0x8001 → profile 자동 할당
  profiles/somfy-blinds-3.yml# component 3개(main, blind2, blind3) 정의
  src/init.lua               # endpoint ↔ component 매핑 + WindowCovering 핸들러
```

## 배포 (SmartThings CLI)

> ⚠️ **인자 주의** — 명령마다 인자가 다르다:
> - `edge:channels:assign`  인자 = **driverId** (채널은 대화형/`--channel`)
> - `edge:channels:enroll`  인자 = **hubId**    (채널은 대화형/`--channel`)
> - `edge:drivers:install`  인자 = **driverId** (허브는 대화형/`--hub`)
>
> **`channelId` 를 인자로 주면 안 된다** — driverId/hubId 자리로 잘못 해석돼 `404 Missing driver`
> 또는 `500` 이 난다. 헷갈리면 **인자 없이** 실행해 대화형으로 고르는 게 가장 안전하다.

```bash
# 0) CLI 설치 (Node 필요)
npm install -g @smartthings/cli

# 1) 패키지화(빌드+업로드) — 끝에 Driver Id 가 출력된다(메모)
smartthings edge:drivers:package ./smartthings-driver

# 2) 배포 채널 생성 — Channel Id 가 출력된다
#  Channel name : somfy-rts-thread
#  Channel description : somfy-rts-thread smartthings
#  url : xxxxx.com, example.com
smartthings edge:channels:create

# 3) 채널에 driver 할당  (인자 없이 → driver 선택 → 채널 선택)
smartthings edge:channels:assign
#   (인자를 줄 거면 driverId 만: smartthings edge:channels:assign <driverId>)

# 4) 내 허브를 채널에 등록  (인자 없이 → 허브 선택 → 채널 선택)
smartthings edge:channels:enroll
#   (인자를 줄 거면 hubId 만: smartthings edge:channels:enroll <hubId>)

# 5) 허브에 driver 설치  (인자 없이 → 허브 선택 → driver 선택)
smartthings edge:drivers:install
#   (인자를 줄 거면 driverId 만: smartthings edge:drivers:install <driverId>)
```

## 기기에 driver 적용
- **이미 페어링된 기기**: SmartThings 앱 → 해당 블라인드 기기 → 점 3개(설정) → **Driver** →
  목록에서 `Somfy Blinds 3-Shade (composed)` 선택. 카드가 3-component 로 다시 그려진다.
- 또는 기기를 삭제하고 재페어링하면 fingerprint(VID/PID)로 이 profile 이 자동 적용된다.

## 동작
- `main` → 첫 WindowCovering endpoint, `blind2` → 둘째, `blind3` → 셋째 (정렬 순).
- 명령: 열기/닫기/정지(`windowShade`) + 위치 %(`windowShadeLevel.setShadeLevel`) + **틸트 %(`windowShadeTiltLevel.setShadeTiltLevel`, arg=`level`)**.
- 위치 변환: Matter `CurrentPositionLiftPercent100ths`(0=열림,10000=닫힘) ↔ ST `shadeLevel`(0=닫힘,100=열림).

## 참고/주의
- SmartThings Matter Lua 라이브러리 버전에 따라 일부 API 명칭이 다를 수 있다. 패키지화 시 오류가 나면
  메시지에 맞춰 `src/init.lua` 를 조정한다(특히 `emit_event_for_endpoint` / `set_*_to_*_fn` / command 시그니처).
- tilt(틸트)도 **포함** — profile 의 3개 component 모두 `windowShadeTiltLevel` capability 선언 +
  `src/init.lua` 에 `CurrentPositionTiltPercent100ths` 구독 / `GoToTiltPercentage` 송신 핸들러 구현
  (command arg = `level`). 펌웨어가 틸트를 7단계 step burst 로 변환한다.
- 근거: SmartThings 는 "한 기기당 driver 1개" 구조라 composed 다중 endpoint 는 커스텀 driver 로만
  3-component 노출이 가능하다(community.smartthings.com/t/composite-matter-device/283091).

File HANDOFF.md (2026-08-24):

# 인수인계 — 다음 세션에서 이어갈 것

> 새 세션을 열고 **"HANDOFF.md 읽고 이어서 작업해줘"** 라고만 하면 된다.

기준: `main` 최신 커밋 (원격 `github.com/kgun2g/somfy-rts-remote-by-thread`)
> 최근 변경 요약은 `git log` 의 커밋 메시지가 가장 상세하다.

---

## ✅ 완료 — 충전률 측정 재활성 (2026-08-11)

`TEMP_NO_CHARGE = 0`. 상세는 `ISSUE_charge_adc_breaks_oled.md` 와
README 「OLED 구동 방식 & 화면 정책」 참조. 요약만 남긴다.

**진짜 원인은 "ADC 가 인터럽트를 끈다" 가 아니라 직렬화 구멍이었다.**
락(`oled_ui_i2c_lock`)이 `_fb_flush` 만 덮어, `_oled_send_cmds`(화면 자동 OFF/ON,
10초마다)와 `_bbo_probe`(미검출 시 5초마다)가 무방비였다. 우선순위가
`btn_handler 10 > somfy_app 4 > oled_ui 3` 이라 somfy_app 이 oled_ui 를 **선점**하고,
비트뱅은 CPU 가 곧 클럭이라 선점당한 전송이 SSD1306 을 고착시켰다(래치).

**수정**: 락 범위를 `_bbo_write()` 자체로 이동 + **재귀 뮤텍스**(flush 가 바깥 락을
쥔 채 부르므로 일반 뮤텍스면 즉시 데드락) + 뮤텍스 생성을 `oled_ui_init` 맨 앞으로.
락 타임아웃 200 ms 시엔 전송을 진행하고 `[OLEDMON] lockTO` 로 계수(정상 = 0).

**측정 주기 5초·표본 8회는 그대로 둘 것** — 줄이면 `_nobat_track` 의
"5분 창 / 반쪽당 30표본" 가정이 깨져 배터리 미연결 오판이 난다.

검증: `sim/tools/adc_oled_mutex_sim.py`(8시드×10분) 수정 전 6/8회 고착(최빠른 80초)
→ 수정 후 0/8.

**★실기 장시간 검증 (2026-08-11 02:15~07:00, COM7)** — 콘솔 `cyc` 로 화면을 계속
갱신시켜 OLED 를 100% 부하로 돌리고 ADC 는 5초 주기로 병행:

| 항목 | 결과 |
|---|---|
| 가동 | **4시간 45분** (17,047초) |
| 전송 | **257,562건** (907건/분) |
| **실패** | **0** (0.000000%) |
| **lockTO** | **0** |
| present | 284개 샘플 **전부 1** (미검출 0회) |
| 패닉·재부팅·워치독·abort·스택오버플로 | **각 0건** |
| OLED 검출실패 / 버스복구 호출 | **0건 / 0건** |
| free heap | 169,152B (첫 샘플 대비 **-80B**) |
| dirty-page 감축 | 98.1% (보냄 51,503 / 건너뜀 2,672,313) |

되돌리려면 `TEMP_NO_CHARGE` 를 1 로.

---

## ✅ 완료 — 배터리 "78%" 오표시 (2026-08-11)

**증상**: 배터리를 안 꽂았는데 충전률이 78% 로 표시됨.

**원인**: 배터리를 빼도 충전 IC 가 BAT+ 를 **3,970 mV** 로 띄우는데, 이 값이 OCV 곡선상
정확히 78% 다. 전압만으론 실제 배터리 78% 와 구분 불가. 구분 단서인 "전압이 오르는가"
판정(`_nobat_track`)은 **5분 창**이 차야 나오므로, 부팅 후 **5분 23초** 동안 78% 가 보였다.
(테스트로 시리얼을 열 때마다 DTR/RTS 로 리셋돼 그 5분이 계속 리셋된 것도 겹쳤다.)

**수정**: 첫 판정 전에는 % 대신 `--%` 표시(`BAT_PCT_UNKNOWN`). 단 **애매할 때만** 숨긴다 —
float 창(3940~4010 mV) 밖이거나 USB 미연결이면 배터리 존재가 자명하므로 즉시 % 표시.

**★창(5분)을 줄이지 말 것.** 충전 상승률 ≈9.3 mV/5분 vs 문턱 4 mV →
3분 창은 2.8 mV 라 **충전 중인 배터리를 "미연결"로 오판**한다.
검증표는 `sim/tools/bat_pct_display_sim.py` 및 `sim/tools/README_oled_sim.md` 부록.

---

## ✅ 완료 — 배터리 단독 부팅 멈춤 (2026-08-11)

**증상**: USB 를 빼고 배터리만 연결하면 부팅 화면에서 멈추고 40초~1분마다 재부팅.
USB 를 꽂으면 정상 — 그래서 시리얼 로그를 볼 수 없었다.

**원인**: `esp_matter::console::init()` 이 CHIP shell 을 **우선순위 5** 태스크로 띄운다
(`somfy_app`=4, `oled_ui`=3 보다 높다). 프롬프트 출력이 `esp_rom_usb_serial_putc` →
`usb_serial_device_tx_flush()` 로 **USB 호스트를 기다리는데**, 호스트가 없으면 이 대기가
길어져 prio 5 가 아래 태스크를 전부 굶긴다.

**수정**: **VBUS(GPIO17)가 있을 때만** CHIP shell 을 시작(`app_main.cpp`
`_usb_vbus_present()`). 콘솔은 개발용이고 `tx`/`sel`/`cyc`/`bd` 도 USB 전용이다.
(`usb_serial_jtag_is_connected()` 는 SOF 기반이라 부팅 1초 시점에 false 가 나올 수 있어
USB 개발 중에도 콘솔이 사라진다 — 그래서 VBUS 핀을 쓴다.)

**진단 도구 — `boot_diag`** (`main/boot_diag.c`, 이번에 새로 만듦):
전원이 끊겨도 남는 **NVS 부팅 단계 기록**. RTC RAM 은 배터리를 빼면 지워져 못 쓴다.
- app_main 경로(`stage`)와 somfy_app 경로(`stage2`)를 **따로** 센다 — 두 태스크가 동시
  진행하므로 단일 카운터로는 어느 쪽이 멈췄는지 구분 불가
- 실패한 부팅은 별도 키(`fail`)에 **영구 보관** — 정상 부팅이 덮어쓰면 증거가 날아간다
  (실제로 한 번 날렸다)
- 콘솔 **`bd`** 로 언제든 조회, `bd clear` 로 삭제
- 끄려면 `BOOT_DIAG_ENABLE 0` (부팅당 NVS 쓰기 ~17회)

**탈락시킨 가설들**: 전원/브라운아웃(배터리 4.02 V, 최저치 동일 — 사그 0), Task WDT
(5초라 주기 불일치), BAT_ADC 로직(해당 코드 미실행), I2C 스캔 NULL 핸들(`sub=10` 이라 미실행).

> ⚠ 진단 중 브라운아웃 임계값을 2.51 V → **2.92 V**(`sdkconfig.xiao-c6`
> `ESP_BROWNOUT_DET_LVL=4`)로 올렸고 **그대로 두었다**. 원인은 전원이 아니었지만,
> 더 민감한 검출은 보호 측면에서 유리하다. 되돌리려면 그 두 줄을 `SEL_7`/`7` 로.

---

## ✅ 완료 — 배터리 % 흔들림 (2026-08-11)

배터리 구동에서 81→82→**74**→84→81 % 로 튀었다. BLE 광고·RF 송신 순간 **실제로**
전압이 떨어지는데(USB 는 레일이 단단해 안 보였다), OCV 곡선상 이 구간은 1 % ≈ 10 mV 다.

표시 경로에만 **중앙값 5주기 + EMA(α=1/4)** 적용(`_bat_smooth_mv`). `_nobat_track` 에는
**원본**을 준다(5분 창 30표본 통계라 평활하면 가정이 깨짐). 측정 주기·표본 수 불변.

★**EMA 는 1/16 mV 단위로 누적**한다 — C 의 정수 나눗셈이 0 쪽으로 절단해 1 mV 단위로
쓰면 차이 1~3 mV 에서 몫이 0 이 되어 EMA 가 고착된다.
검증: `sim/tools/bat_pct_smooth_sim.py` (진폭 19→9 %p, 주기간 변동 4.09→0.38 %p).

---

## ✅ 완료 — 화면 OFF 시간 전원별 분리 (2026-08-11)

| 전원 | 매크로 | 값 |
|---|---|---|
| USB | `CFG_SCREEN_OFF_USB_SEC` | **300초(5분)** |
| 배터리 | `CFG_SCREEN_OFF_SEC` | 10초 |

---

## 남은 과제

### 1. 진동센서 — 소프트는 해결, **하드웨어 고장은 남음**

★2026-08-11 정정: "stuck 판별이 발동 안 한다"는 이전 기록은 **틀렸다**. 실기에서 발동한다.

```
W (21051) BTN: [VIBE] 센서 고장 판정(핀 고정) (최근 200샘플 HIGH=200) — 진동 무시함
```

덕분에 화면도 정상적으로 꺼진다(유휴 캡처에서 60초 이후 전송이 멈춘 채 200초 이상 유지).
→ **"화면이 저절로 켜져 안 꺼진다"는 해결됨.**

다만 근본은 하드웨어다. VIBE 핀이 **300/300 전부 HIGH 고정**이라 진동을 아예 못 읽는다.

- 현재 영향: **진동으로 화면을 깨울 수 없다**(버튼으로만 깨어남). 소프트로는 더 할 게 없다.
- 할 일: VIBE 핀(GPIO0)·VS1 진동 스위치 배선/납땜 점검. 핀이 계속 HIGH 면
  스위치 단선 또는 GND 미연결이 유력.
- 판정 로직은 `button_handler.c` 의 `VIBE_STUCK_WIN`(200샘플) — 건드릴 필요 없음.

### 2. ESP32-H2 메모리
블라인드 3개에서 **free heap 4,712B / 최대블록 2,432B**(C6 는 171KB). BLE 커미셔닝 불가.
→ H2 는 `BLIND_MAX_COUNT` 를 **2 이하**로.

### 3. COM4 하드웨어
SDA·SCL 둘 다 `0/0/0`. v4 는 PCB 풀업이 없으므로 이는 **모듈 VCC 가 0V** 라는 뜻.
→ 멀티미터로 OLED 모듈 VCC 측정. 0V 면 전원 경로(냉납·단선), 3.3V 면 모듈 손상.

### 4. OLED 장시간 고착 관찰
충전측정을 꺼도 **7시간 뒤 고착**된 이력이 있다(실패율 0.02%→12.5%).
dirty-page 감축(전송 75%↓) 이후 재발 주기가 늘었는지 `[OLEDMON]` 으로 확인.
근본 대책은 **모듈 VCC 를 GPIO+MOSFET 으로 제어**해 자동 전원 리셋(4핀 SSD1306 은 RES 핀이
없어 전원 차단만이 복구 수단).

### 5. WASM 시뮬레이터 복구 (선택)
`sim/wasm/build.ps1` 이 실제 `oled_ui.c` 를 컴파일하는데 stub 헤더가 없다
(`driver/gpio.h`, `soc/gpio_reg.h`, `soc/io_mux_reg.h`, `soc/lp_aon_reg.h`, `esp_rom_sys.h`).
이 include 들은 2026-07-17 부터 있던 것으로 **이번 변경 때문이 아니다.**
`emcc` 미설치 + 빌드 산출물 없음 → 한동안 미사용.
되살리려면 emcc 설치 → 빌드 → **컴파일러가 알려주는 에러대로** stub 추가(추측 금지).

---

## 보드 현황

| 포트 | 보드 | 옵션 | 상태 |
|---|---|---|---|
| COM7 | xiao-c6 (h4 신PCB) | `-Pcf 8575 -Rotary ec05 -Oled 128x64 -Rotate 180 -Freq 447.70` | 최신 |
| COM4 | xiao-c6 (v4 구PCB) | `-Pcf 8574` (좌/우 버튼 없음) | 커밋 `a3694d3` 시점 / OLED HW 문제 |
| COM3 | esp32-h2 | `-Pcf 8574 -Rotate 180` | 최신 / 메모리 한계 |

> ★COM3 의 **`-Rotate 180` 은 필수**다(2026-08-13 표 보완). H2 시제품은 OLED 가 180°
> 뒤집혀 장착돼 있고 `boards/esp32-h2.h` 기본값은 `BOARD_OLED_ROTATE_180 0` 이라,
> 옵션을 빼고 구우면 **화면이 상하반전**된다. `doc/wiring/wiring_esp32-h2.md:13` 에는
> 원래 적혀 있었는데 이 표에서 누락돼 실제로 한 번 당했다(2026-07-02).

빌드 예:
```bash
./build.ps1 -Board xiao-c6 -Action flash -Port COM7 -Pcf 8575 -Rotary ec05 -Oled 128x64 -Rotate 180 -Freq 447.70
```

---

## ★절전 측정 현황 (2026-08-24 갱신)

> **결론 먼저 (2026-08-25 시점, 두 보드 모두 완료)**
>
> | | C6 | H2 |
> |---|---|---|
> | 잠 | **96.2%** | **96.6%** |
> | 깨어남 | **23.7회/초** | **33.2회/초** |
> | 방전 | **8.7 mV/시간** | — |
> | free heap | 197 KB | **40.5 KB** (11.3 → +29.2) |
> | 방식 | LP 코어 눌림 래치 + ULP 깨움 | **PCF `~INT` 레벨 트리거** |
>
> C6 는 깨어있는 시간 13.4% → **3.6%**, 700mAh 로 약 5일.
> H2 는 **0.0% → 96.6%** — `bt` 락 제거(적용 누락이었다) + `~INT` ISR.

### 기여도 (C6, 배터리 유휴 실측)

| 조치 | 깨어있는 시간 | 비고 |
|---|---|---|
| 시작 | 13.4% | |
| `-Os`(그동안 IDF 기본 `-Og` 였다) | 11.9% | 회당 1.52 → 1.35ms |
| 상시 계측 끄기(PM_PROFILING·RUN_TIME_STATS) | 10.7% | 회당 1.20ms |
| 802.15.4 수면 중 전원차단 | (약 5%) | 같은 전압구간 8.37 → 8.94h |
| LP 눌림 래치 + 폴 25→100ms | 11.3% | 깨어남은 줄었으나 회당 시간이 늘어 상쇄 |
| **iot_button 20ms 타이머 제거** | **3.6%** | ★단독으로 나머지 전부보다 컸다 |

### ★★★2026-08-24 — 깨어남의 78% 는 **쓰지도 않는 예제 버튼**이었다

배터리 실측에서 **125만 회 수면 중 20ms 를 넘은 것이 한 번도 없었다.** 버튼 폴을
100ms 로 늘린 뒤에도 그대로였고, 깨어난 원인은 99.97% 가 TIMER(=예약된 알람)인데
우리 태스크 주기는 100/100/500/500ms 뿐이라 12~20ms 를 만들 게 없었다.

→ 콘솔 **`tmr`**(`esp_timer_dump`)로 찍으니 등록된 타이머가 딱 하나였다:

```
Name          Period   Times_trigg   Cb_exec_time
button_timer  20000    10743         60767 us      ← 초당 50회
```

`espressif__button`(iot_button)이 `CONFIG_BUTTON_PERIOD_TIME_MS`(20ms) 주기
esp_timer 를 **상시** 돌리고 있었다. esp-matter light 예제에서 복사돼 온 잔재로,
공장초기화(BOOT 5초 롱프레스) 하나에만 쓰였다. 실제 조작 버튼은 전부 PCF8575 →
`button_handler` 가 처리한다. 사용자 확인 후 **통째로 제거** → `tmr` 출력 타이머 0개.

> **★교훈: 추정하지 말고 찍어라.** 이 하나를 찾기까지 내가 세운 가설이 세 번 틀렸다.
> (1) 배터리 구간 LP 코어 정지 → `LP=ON` 확인으로 반증
> (2) LP 가 PCF 지터로 HP 를 깨움 → `[LPWAKE] HP 깨우기 0.00회/초` 로 반증
> (3) Matter/OpenThread 내부 타이머 → **실제로는 우리 코드**
> `esp_timer_dump()` **한 줄**이 세 번의 추정을 끝냈다.

### ★2026-08-24 — H2 는 왜 아직도 안 자나: 8/15 수정의 **적용 누락**

H2 배터리 13.9시간 실측: `sleep 0.0%`, 그런데 batlog 의 `pm` 열은 **3**
(= light sleep ON + 배터리) — **설정은 정상인데 실제로 안 잔다.**
NVS 로 받은 `esp_pm_dump_locks`:

```
Name   Type            Active  Total_count  Time(%)
bt     APB_FREQ_MAX      1          1        100%    ← 부팅부터 한 번 잡고 안 놓음
rtos0  CPU_FREQ_MAX      1       657888        6%
I2C_0  NO_LIGHT_SLEEP    0        60162        2%
Mode:  APB_MAX 94% / SLEEP 0%
light_sleep_counts:0   reject_counts:0        ← 시도조차 안 함
```

**2026-08-15 에 이미 찾아 고쳤던 그 `bt` 락이다.** 당시 조치
(`CONFIG_USE_BLE_ONLY_FOR_COMMISSIONING=y`)가 **C6 오버레이에만** 들어갔다:

```
sdkconfig.defaults.xiao_c6    ...=y     ← C6 만
sdkconfig.defaults.h2_thread  ...=n     ← H2 는 n 그대로
sdkconfig.defaults.c6_thread  ...=n
```

> **★교훈: 보드별 오버레이 구조에서 "고쳤다"는 한 보드에서만 참일 수 있다.**
> 공통 결함을 고치면 **모든 보드의 defaults 를 확인**할 것.
> (같은 성격의 사고: `g_wake_iter` 정의가 batlog 가드 안에 있어 H2 링크가 깨진 건 — 커밋 a6e5f72)

### ★★2026-08-25 — H2 는 `~INT` 를 쓸 수 있었다 (C6 결론을 일반화한 것이 오류)

`bt` 락을 푼 뒤 H2 는 깨어남이 **113.9회/초**였다(C6 는 23.7). PM 락 덤프가 이유를
보여줬다 — `I2C_0 NO_LIGHT_SLEEP` 을 **748,352회** 잡았다 놓는다. H2 는 LP 코어가
없어 버튼을 10ms 마다 HW I2C 로 직접 읽기 때문이다. C6 에서 쓴 LP 눌림 래치는
LP 코어가 전제라 H2 엔 못 쓴다.

코드 주석에는 *"`~INT` 는 이 하드웨어에서 쓸 수 없다"* 고 단정돼 있었다. 그런데
그 실측은 **C6 조건**(비트뱅 I2C, GPIO2)이었고 **H2 에서 재본 적이 없었다.**
사용자 지적으로 다시 쟀다:

```
H2  [INTOBS] 표본 16,675  LOW 18(0.1%)  ★전이 36     ← 누르면 선이 움직인다
C6  intdiag  표본 290,023 (버튼 조작 중)  전이 0회    ← 선이 죽어 있다
```

| | 이전(0.0%→) | `bt` 락 제거 | **+ `~INT` ISR** |
|---|---|---|---|
| 잠 | 0.0% | 88.8% | **96.6%** |
| 깨어남 | — | 113.9회/초 | **33.2회/초 (−71%)** |
| 회당 잠 | — | 7.8ms | **29.1ms** |

> **★내가 두 번 틀렸다.** (1) 기존 주석의 "이 하드웨어"를 그대로 믿었다.
> (2) 정지 상태에서 `~INT` 0건인 것을 "조용하다=쓸 수 있다"로 오독했다 —
> **정지 상태의 0건은 아무것도 증명하지 않는다.** 관건은 **누를 때 움직이는가**다.
> 그 오독으로 ISR 을 잘못 걸어 **인터럽트 WDT 재부팅을 44회** 냈다.

**`~INT` 를 다른 보드에서 검토할 때의 절차** (이번에 확립):

1. **ISR 없이 먼저 관찰** — 폴링이 핀 레벨을 같이 보게 해 전이를 센다(`[INTOBS]`).
   ISR 을 먼저 걸면 폭주 시 인터럽트 WDT 로 재부팅한다.
2. **버튼을 누르는 동안** 전이가 늘어나는지 볼 것. 정지 상태 0건은 무의미.
3. 살아 있으면 **레벨 트리거**로 건다. `~INT` 는 레벨 신호라 `NEGEDGE` 는 안 된다 —
   이미 LOW 면 엣지가 안 오고, read 해제 순간의 상승·재하강이 겹치면 ISR 이 몰린다.
   ISR 안에서 **즉시 자기 인터럽트를 끄고**(IRAM-safe `gpio_ll_intr_disable`),
   태스크가 포트를 읽어 **HIGH 로 돌아온 뒤에만** 재활성한다.
   등록은 **초기 read 뒤** — LOW 인 채로 등록하면 레벨 트리거가 즉시 폭주한다.
   (진동 ISR 이 X160 chatter 를 막는 방식과 동일한, 검증된 패턴)

### 측정 방법 — 반드시 지킬 것

**같은 출발 전압 · 같은 도착 전압으로 비교한다.** OCV 곡선 기울기가 구간마다
**2.3배** 다르기 때문이다(3850~3950 = 5.0mV/%p, 4080~4150 = 11.7mV/%p).
실제로 이걸 어겨 duty 가 다른 두 세션을 연립했다가 **수면 전류 −9.8mA** 라는
불가능한 값이 나온 적이 있다 — 차이는 duty 가 아니라 측정 구간이었다.

도구: `sim/tools/bat_current_estimate.py`(방전→실효 전류 역산),
`sim/tools/batlog_decode.py`(수면 길이 히스토그램·깨어남 원인·태스크별 반복),
`sim/tools/pmdump_decode.py`(PM 락 보유자).

※멀티미터 직렬 전류 측정은 **불가**(이 기판은 배터리 선을 끊을 수 없다).
  배터리 +/− 에 전류계 모드로 직결하면 **셀 단락** — 절대 금지. 전압만 잰다.

---

## 절전 측정 현황 (2026-08-14, 이력)

**비교는 반드시 "동일 전압 구간의 기울기"로 한다.** % 는 1%p 양자화 + OCV 곡선
비선형이고, 저 SoC 에서는 부하 강하가 커져 전체 평균 % 로 비교하면 왜곡된다.
세션 조건(`radio` / `screen` / `pm`)이 같은지도 같이 확인할 것 — 배터리 기록의
각 행에 들어 있다(`bl` 콘솔 명령).

| 세션 | 구성 | 길이 | 3790~4000mV 구간 | 환산 |
|---|---|---|---|---|
| #22 | 개선 전 (tick **100Hz**, LP 없음) | 6.64h | −0.67 mV/분 | **47.4mA** |
| #32 | ①tick **1000Hz** + ③LP 코어 | 7.70h | −0.75 mV/분 | **52.7mA** |

세부 4구간 중 3개 악화 + 1개 동일, 개선된 구간 **없음**. 두 세션 모두
`radio=1 / screen=OFF / pm=3` 로 조건 동일(#22 는 화면 ON 11% 포함 = 오히려 불리).

⇒ **①(tick 1000Hz)은 절전이 아니라 소폭 악화.** 2026-08-14 **100Hz 로 되돌렸다.**

> ★되돌리기 전에 반드시 했어야 하는 일: `pdMS_TO_TICKS` 는 정수 내림이라
> 100Hz 에서 **10ms 미만 대기가 0 tick = 소멸**한다. `vTaskDelay(0)` 은 yield 라
> 대기가 통째로 사라진다. 해당 4곳을 `esp_rom_delay_us()` 로 교체 완료:
> `somfy_rts.c:339/415`(5ms VCO/PA settle — SDR 실측으로 넣은 것),
> `cc1101.c:365`(2ms SCAL), `somfy_app.c:3399`(3ms CHG_STAT 풀업 안정).
> **tick 을 다시 건드릴 때는 `vTaskDelay(pdMS_TO_TICKS(x))` 전수 재검사할 것.**

100Hz 실기 확인: 부팅 정상, `tx up 3000` = 3.29초/23프레임(1000Hz 는 3.44초/24).
프레임이 오히려 촘촘해진다(1000Hz 는 프레임당 +4.81ms 여분 틈이 생겼다).

### ★★★진짜 원인 발견 (2026-08-15) — light sleep 은 한 번도 진입한 적이 없었다

`CONFIG_PM_PROFILING=y` + 콘솔 `pm`(`esp_pm_dump_locks`)으로 **계측**했다:

```
Lock stats                     Active  Total_count  Time(%)
  bt        APB_FREQ_MAX          1        1          100%   ★
  rmt_0_0   CPU_FREQ_MAX          1        1          100%   ★
  ot_sleep  APB_FREQ_MAX          0       59            1%
Mode stats:  CPU_MAX 160M  99%      ← light sleep 항목 자체가 없음
```

락 두 개가 부팅부터 100% 잡혀 있어 **automatic light sleep 이 진입 자체를 못 했다.**
①(tick)·③(LP 코어)이 3회 측정에서 전부 눈금에 안 잡힌 이유가 이것이다 —
CPU 가 CPU_MAX 에서 내려온 적이 없으니 **CPU 쪽 조치는 효과가 있을 수 없었다.**

| 조치 | 내용 | 결과 |
|---|---|---|
| `rmt_0_0` | `rmt_enable()` 이 CPU_FREQ_MAX 락을 잡는다. 부팅 때 켜고 계속 뒀다 → **burst 동안만** 켜도록(`_rmt_acquire`/`_rmt_release`, 경계는 `cc1101_enter_tx_mode`…`cc1101_idle`). `rmt_disable` 은 진행 중 전송을 자르므로 `rmt_tx_wait_all_done()` 로 먼저 비운다 | **CPU_MAX 99% → 5%** |
| `bt` | `CONFIG_USE_BLE_ONLY_FOR_COMMISSIONING` 이 CHIP 기본값 y 인데 우리는 꺼져 있었다(esp-matter 예제 기본값이 이유 없이 따라옴). 켜면 등록 후 BLE deinit + 이미 provisioned 면 부팅 시 초기화조차 안 함 | **`bt` 락 소멸, 힙 164→184KB** |

수정 후: `APB_MIN 90% / APB_MAX 3% / CPU_MAX 6%`, 락 목록 깨끗.
※USB 에서는 설계상 light sleep 을 끄므로(USB-JTAG 보호) **진입 여부는 배터리에서만** 보인다.

### ★계측을 NVS 로 남긴다 (2026-08-15)

이 보드는 **포트를 여는 순간 리셋**된다(`리셋사유=USB리셋(플래시/포트열기)`).
그래서 `esp_pm_dump_locks` 의 RAM 통계는 **읽으러 가는 행위가 지워버린다** —
실제로 배터리 구간 통계를 그렇게 날렸다.
→ `CONFIG_PM_LIGHT_SLEEP_CALLBACKS=y` + `esp_pm_light_sleep_register_cbs` 의 exit
콜백이 주는 **실제 `sleep_time_us`** 를 누적해 배터리 로그 행(`bat_sample_t.ls`)에
싣는다. `bl` 한 번으로 방전 기울기와 sleep% 를 같은 표에서 본다.

```
BL   12  + 1436s  3869mV   62%  avg  70mA  radio=1 screen=0 pm=3  sleep 87%  산포  2( 3mV)  주기
                                                                  ^^^^^^^^^
```

### 남은 후보 (기대값 순)

| 순서 | 조치 | 상태 (2026-08-24 갱신) |
|---|---|---|
| 0 | 락 해제 후 방전 측정 | **완료 (C6)** — 96.2% 수면, 8.7mV/h |
| 1 | 라디오 MAC/BB 전원차단 | **완료** — 단 `ESP_PHY_MAC_BB_PD` 가 아니라 **`IEEE802154_SLEEP_ENABLE`** 이다(전자는 Wi-Fi/BLE 용이고 RAM 2~4KB 더 먹는다). 실측 약 5% |
| 2 | CC1101 `SPWD` (송신 안 할 때 절전) | **미시도** (데이터시트 ~1.7mA 추정) |
| 3 | btn_task 유휴 주기 25ms → 100ms | **완료** — 단 주기만 늘리면 "너무 느리다"로 되돌아온다(8/20 실패). LP 눌림 래치 + LP→**태스크** 즉시 깨움이 전제. 결과적으로 반응은 25ms → **3~5ms 로 오히려 빨라짐** |
| 4 | 메인 루프·hold_repeat 깨움 | **미시도** — 합쳐 12회/초. 지금 전체가 23.7회/초라 비중이 커졌다 |
| 5 | H2 `bt` 락 제거 | **완료** — `h2_thread`·`c6_thread` 를 `y` 로(gnpe-c6 도 함께 구제). H2 0.0 → 88.8 %, free +29.2 KB |
| 6 | H2 `I2C_0` NO_LIGHT_SLEEP 락 | **완료** — PCF `~INT` 레벨 트리거로 유휴 폴 10 → 50 ms. H2 113.9 → **33.2 회/초, 96.6 %** |
| 7 | C6 메인 루프(10 회/초) + hold_repeat(2 회/초) | **미시도** — 전체가 23.7 회/초라 이제 **비중 절반**이다. 다음 지렛대 |
| 8 | H2 `~INT` 를 C6 에도? | **불가** — C6 는 `intdiag` 실측상 전이 0회(죽은 선). LP 코어 래치가 그 역할을 한다 |

### 현재 남은 병목 (2026-08-25)

두 보드 모두 96 %대에 도달해 **더 줄일 여지가 크지 않다.** 남은 것은:

| 보드 | 깨어남 내역(추정) | 비고 |
|---|---|---|
| C6 23.7 회/초 | 메인 루프 10 + btn 10 + oled 2 + hold 2 | 우리 태스크가 거의 전부 |
| H2 33.2 회/초 | 유휴 폴 20 + 메인 루프 10 + 기타 | `~INT` 안전망 폴이 절반 |

메인 루프(100 ms)를 늘리는 것이 다음 후보지만, **회당 깨어있는 시간이 늘어 상쇄될 수
있다** — C6 에서 btn 폴을 25 → 100 ms 로 늘렸을 때 깨어남은 −28 % 였는데 깨어있는
시간은 오히려 늘었다(1.15 → 1.77 ms). 반드시 **깨어남 횟수가 아니라 깨어있는 시간**
으로 판정할 것.

### LP 눌림 래치를 쓸 때 반드시 함께 해야 하는 것 (2026-08-23)

주기만 늘리면 **지연이 그대로 체감된다**(8/20 100ms 시도 → "너무 느리다" → 되돌림).
셋이 모두 있어야 한다:

1. **LP 눌림 래치** (`lp_core/pcf_poll.c` `press_latch`) — 폴 사이의 짧은 누름을 OR 로
   모은다. **로터리 A/B 는 제외**(회전 중 토글해 영구 눌림으로 굳는다 — 실제로 겪음),
   **2연속(4ms) 디바운스**(래치는 2ms 글리치도 전부 잡으므로 한 번 거른다).
2. **LP → 태스크 즉시 깨움** — IDF 에 LP→HP 인터럽트 API 가 **없다**
   (`ulp_lp_core_sw_intr_trigger` 는 HP→LP 방향). light sleep **복귀 콜백**에서
   `esp_sleep_get_wakeup_cause() == ESP_SLEEP_WAKEUP_ULP` 를 보고 통지하는 것이 유일한 통로.
   ★`vTaskDelay` 는 통지로 못 깨운다 — `ulTaskNotifyTake` 로 바꿔야 한다.
3. **`esp_sleep_enable_ulp_wakeup()`** — ★이게 빠지면 2번이 통째로 죽는다.
   실측: 등록 전 ULP 깨움 **0건** → 등록 후 버튼 10회에 **11건**.

> ★**light sleep 은 아직 한 번도 진입한 적이 없을 가능성이 크다.** 문턱은
> `FREERTOS_IDLE_TIME_BEFORE_SLEEP=3` tick 이고(FreeRTOS 최소값 2라 더 못 낮춘다),
> 100Hz 에서 3 tick = **30ms**. 그런데 btn_task 유휴가 25ms → `pdMS_TO_TICKS(25)`
> = 2 tick = 20ms 로 깨어난다 → 문턱을 못 넘는다.
> `pm=3` 은 "esp_pm_configure 가 light sleep 을 **허용**했다"는 뜻일 뿐
> **실제로 자고 있다는 증거가 아니다.** 라디오(~60mA)가 지배 항목이므로
> 1번(MAC_BB_PD)부터 가는 게 기대값이 크다.

## ✅ 완료 — PROG 긴 누름 무응답 (2026-08-15)

**증상**: PROG 를 2초 이상 눌러도 블라인드가 반응하지 않음(짧게는 정상, 정품은 동작).
훨씬 이전부터 있던 문제.

**원인**: `_build_frame` 이 **byte7 을 전 프레임 `0x84` 로 고정**하고 있었다.
정품(그리고 ESPSomfy)은 **재전송마다 byte7 을 올린다** — 첫 프레임 `0x84`,
재전송 `196 + rep*4` (= `0xC4, 0xC8, 0xCC, …`).

**수정**: `somfy_rts.c` 송신 루프에서 프레임마다
`frame[7] = first ? 0x84 : _encode80_byte7(196, i-1)` 로 갱신하고,
체크섬이 byte7 을 입력으로 받으므로 `frame[9]` 도 함께 재계산한다.
(조합 명령 UP+DOWN/MY± 은 byte9 가 실측 고정값이라 제외.)
**타이밍은 건드리지 않았다** — 과거 "byte7 가변 → 모터 무응답" 기록은 타이밍
표준값과 묶어서 바꾼 것이라 byte7 이 누명을 썼던 것으로 보인다.

### ★★★이 건에서 이틀 돈 이유 — rtl_433 표시값 ≠ wire 바이트

송신은 b[1..6]만 체인 XOR 하지만 **rtl_433 풀 디코더는 b[1..9] 전체를 디스크램블**한다
(`ESPSomfy-RTS/SOMFY_RTS_447.md` 에 명시돼 있다). 따라서

```
표시 b8 = wire b8 ^ wire b7        표시 b9 = wire b9 ^ wire b8
```

콘솔 `tx8` 로 raw byte8 을 스윕해 8/8 실증했다(`H4_02.json`):

| raw | 0x00 | 0x20 | 0x40 | 0x44 | 0x48 | 0x4C | 0xC4 | 0x60 |
|---|---|---|---|---|---|---|---|---|
| 표시 | 84 | A4 | C4 | C0 | CC | C8 | 40 | E4 |

> **오독 경위(반복 금지)** — 정품이 짧게 `84/A4/A8`, 길게 `C4/E4/E8` 로 보여
> "bit 0x40 = 누르고 있음(hold 코드)" 이라고 판단하고 그걸 구현했다가 **멀쩡하던
> 긴 누름까지 깼다**. 실제로는 wire b7(재전송 인덱스)이 XOR 되어 그렇게 보인 것이고
> **hold 코드는 존재하지 않는다**. 정품 81건 역산에서 75건(93%)이
> `0x84`(첫 프레임)/`0xC4`(재전송0)/`0xC8`(1)/`0xE8`(9)/`0xFC`(14) 로 설명된다.
> 나머지 6건은 `0xFD` 로 계열 밖 + byte9 불일치 = 디코드 오류.
> **표시값을 wire 값으로 착각하지 말 것.**

### 참조 구현을 먼저 볼 것

`D:\dev\workspaces\ESPSomfy-RTS` — 사용자가 447MHz 2-FSK 대응을 추가한 fork.
`SOMFY_RTS_447.md`(설계 근거) + `Somfy.cpp` 의 `encode80BitFrame` /
`encode80Byte7` / `sendFrame`. 우리 `somfy_rts.c` 와 구조가 사실상 같다.
전 항목 대조 결과 프레임 내용·프레임 수는 일치하고, 타이밍은 우리가 실측에 더 가깝다
(SYMBOL 644 vs 640, SW sync 4840 vs 4850, interFrame 3916 vs 4000).
**프로토콜 의문이 생기면 SDR 분석 전에 여기부터 볼 것.**

## ★RF 실측 데이터 — 추측하지 말고 여기서 확인할 것

| | 경로 |
|---|---|
| 정품 리모컨 SDR 캡처 | `D:\RTL_SDR\sdrsharp-x64\somfy_rts_447` |
| 분석 스크립트 + 절차 문서 | `D:\dev\workspaces\plugin-Rtl433-for-SdrSharp-master\scripts` (README.md §0, §7) |

캡처는 `1. up` / `2. down` / `3. my` / `4. prog` / `5. tilt up` / `6. tilt down` 로
버튼별 폴더, 그 아래 게인별 하위폴더(`3_42.1dB` 등). **한 wav = 버튼 한 번 누름.**

```bash
python diag_iq.py <정품.wav> <우리.wav>   # burst 위치/길이 (인자 2개 필수)
python dump_burst.py <wav>                # 펄스열 — HW/SW sync 개수
python measure_rf.py <wav>                # deviation / carrier offset / 타이밍
```
※경로에 공백이 있어 셸에서 `$(ls ...)` 로 넘기면 인자가 쪼개진다. Python 으로 돌릴 것.

> ★**캡처에는 "일부러 길게 누른 것"이 섞여 있다.** 사용자가 짧게/길게를 구분하라고
> 넣어둔 것이다. 한두 개만 보고 "이 버튼은 원래 길다"고 결론내면 틀린다 —
> 반드시 **전수 중앙값**으로 볼 것. 실제로 그 오독으로 PROG 특수처리가 들어갔었다
> (2026-08-13 제거). 전수 측정 결과 송신 길이는 **전 버튼 350~400ms 동일**이고,
> HW sync 도 prog 29/34/29 vs down 36/36/36/36 으로 **PROG 가 오히려 적다**.
> 정품 구조는 분석 README 에 "HW sync 12회(첫 프레임)/6회(재전송), 버튼 구분 없음"
> 으로 이미 적혀 있었다.

### 길게 누름 = **끊김 없는 한 덩어리** (2026-08-13 확정)

같은 캡처를 10ms 창으로 다시 본 결과(`scratchpad/hold_pattern.py`), ON 길이 분포는

```
300~399ms 765개 · 400~499 41 · 600~699 4 · 700~799 7 · 900~999 3 · 1300~1399 4
1. up  g066  910          ← 910ms 가 통째로 하나의 ON
3. my  g107  1360         ← 1360ms 도 하나
1. up  g070  340 [90] 670 ← 뗐다 다시 누른 것
```

즉 **정품은 누르고 있는 동안 조각내지 않고 계속 쏜다.** 간격이 보이는 캡처는
전부 별개 누름이다. 우리 펌웨어도 이 구조로 맞췄다(아래 함정 절 참조).

## 진단 콘솔 명령 (USB 시리얼)

| 명령 | 용도 |
|---|---|
| `bl` / `bl clear` | 배터리 방전 기록(NVS) — 전압·%·평균전류·**sleep%**·ADC 산포 |
| `pm` | `esp_pm_dump_locks` — PM 락 보유 + 절전모드 체류(진단 빌드 전용) |
| `tx <cmd> [hold_ms]` | RF 송신 (up/down/updown/myup/mydown/my/prog) |
| `tx8 <hex> [cmd] [hold]` | **raw byte8 강제 지정** 송신 — rtl_433 표시값과의 대응표 작성용 |
| `intpd` | `~INT` 풀다운 진단 — 배선단선 vs PCF측 고장 판별 |
| `intdiag` | `~INT` 선 관찰(15초, 버튼 조작 필요) |
| `vl` / `bd` | 진동센서 기록 / 부팅 진단 |

> ★시리얼 접속은 `write_timeout` 을 반드시 설정할 것. 안 그러면 write 가 hang 한다.
> 그리고 **포트를 여는 것만으로 기기가 리셋된다** — RAM 통계는 그때 날아간다.

## ★반드시 알아야 할 함정

- **`somfy_rts_abort` 는 프레임 경계(≈143ms)에서 딱 1번만 검사된다.**
  그래서 `abort=true; delay(20); abort=false;` 같은 **짧은 펄스는 그냥 놓친다** →
  끊으려던 job 이 안 죽고 `max_loops`(hold_ms 15s ⇒ 15.3초)까지 살아버리고,
  새 job 은 직렬 worker 뒤에 줄서서 **버튼 뗀 뒤에 나간다**.
  반드시 **레벨로 세워둔 채** `s_rf_tx_busy=false && 큐 빔` 을 확인하고 해제할 것.
  (`_hold_repeat_task` 의 `s_combo_pending` 상태머신이 이 방식이다.)
- **버튼 PRESS 는 같은 cmd 가 송신 중이면 새 job 을 만들면 안 된다**
  (`_send_command_press` → `_rf_same_cmd_inflight`). PRESS 가 `somfy_rts_abort=false`
  로 중단요청을 해제하므로, 연타 시 job 을 하나 더 넣으면 이전 job 이 abort 를
  못 만나 15초 폭주한다. `sim/tools/hold_gap_sim.py` 케이스 ⑦ 참조.
- **`_hold_repeat_task` 는 누름과 위상이 맞지 않는 자유주행 태스크다.**
  "500ms 주기니까 최대 500ms 지연"이 아니라, 게이트(500ms)+위상까지 겹쳐
  위상 스윕 실측 **최악 561ms 공백**이 나왔다. 주기 기반 재송신으로 연속성을
  만들려 하지 말 것 — 한 job 이 스스로 길게 쏘게 해야 한다.
- **PCF8574 `~INT`(GPIO2) 는 쓸 수 없다 — 2026-08-13 실측 확정.** 절전을 위해
  10ms 폴링을 인터럽트 기반으로 바꾸려는 시도(②)는 **이 하드웨어에서 불가능**하다.
  콘솔 `intdiag` 로 폴링을 멈춘 채 관찰한 결과:

  | 조건 | 표본 | 결과 |
  |---|---|---|
  | 정지 상태 | 38,765 | HIGH 100% / **전이 0회** |
  | **버튼 조작 중 15초** | **290,023** | HIGH 100% / **전이 0회** |
  | 폴링 동작 중 | 33,198 | HIGH 100% / 전이 0회 |

  회로도상 풀업(`R3 10k → +3V3`)은 **정상적으로 있다**(kicad/somfy_blinds_h4). 그런데
  버튼을 눌러도 선이 안 움직인다 → PCF8574 가 `~INT` 를 구동하지 못하는 상태
  (배선 미연결 또는 IC INT 출력 불량). **풀업 추가는 해결책이 아니다** — 이미 있다.
  → ② 를 다시 시도하기 전에 **반드시 `intdiag` 로 전이가 잡히는지 먼저 확인**할 것.

  **데이터시트 대조(`doc/parts/pcf8575.pdf`)로 대안 가설이 전부 배제됐다** —
  INT sink `IOL 1.6mA` vs 우리 부하 0.33mA(풀업 무관) · `tiv 4µs`(샘플링 무관) ·
  *"reading/writing **another device** does not affect the interrupt circuit"*(OLED 무관).
  게다가 *"resetting … when data on the port is **changed to the original setting**"* 이라
  **버튼을 누르고 있는 동안 INT 는 LOW 로 유지**된다(누름당 100ms+). 290,023 표본에서
  전이 0회는 "짧은 펄스를 놓쳤다" 로 설명 불가 = **선이 정말 안 움직인다.**
  고장 위치는 `intpd`(GPIO2 내부 풀다운+ADC, 풀다운 시 2508mV → 상단 풀업 ≈14k)로
  **R3 ~ U3 pad1 구간**으로 좁혀졌다 → **pad1 재납땜 먼저**. 자세한 건
  `doc/wiring/wiring_xiao-c6.md` 의 `~INT` 절.

  ★★**`intdiag` 는 LP 코어 폴링을 멈춰야 한다**(2026-08-15 수정). PCF 읽기가 INT 를
  해제하는데 LP 가 2ms 마다 읽으므로, 안 멈추면 관찰 구간이 통째로 HIGH 로 보인다.
  최초 측정(13:46, `1bbcbc5`)은 LP 도입(18:54, `f45ac86`)보다 5시간 앞서 이 문제가
  없었지만, **재검증 시에는 이 수정 없이는 무조건 "여전히 죽음" 이 나온다.**
  ※폴링과 INT 는 원리적으로 공존이 어렵다 —
  *"Interrupts that occur during the ACK clock pulse **can be lost**"*.
  ※`~INT` ISR 을 등록해두면 **초당 약 4,500회 폭주**해 prio 10 버튼 태스크를 짓밟아
    **버튼이 통째로 죽는다**(실측 540,522회/120초). 선은 조용하므로 전기 신호가 아니라
    `_vibe_isr_handler` 의 `gpio_ll_intr_disable`/`gpio_intr_enable` 반복과의 간섭으로
    본다. 이걸 "진단용이라 무해"하다고 남겨뒀다가 버튼을 두 번 죽였다.
- **진동센서(X160)는 배선이 아니라 센서 자체가 죽을 수 있다.** 2026-08-13 에 세 번
  재납땜하며 배선을 의심했는데, 증상이 `GND 고정(0/300)` → `HIGH 고정(300/300)` 으로
  바뀌기만 했다. **센서를 교체하니 즉시 정상**(평상시 LOW, 흔들 때 HIGH 1~75/273).
  → 판정은 콘솔 `vl`(NVS 진동 기록)로. `섞인 창`이 0 이면 센서가 한 번도 동작 안 한 것.
  정상 기준은 H2(COM3)와 같은 패턴이다.

- **로그 인코딩은 캡처 경로마다 다르다.** pyserial 직접 캡처 = **UTF-8**,
  빌드 로그(`logs/*.log`) = **CP949**. 틀리게 디코드하면 한글 에러가 **0건으로 오독**된다.
  → `try utf-8 → except cp949`. 이것 때문에 "에러 0, 해결됨"이라고 잘못 보고한 적 있음.
- **화면이 꺼지면 OLED 부하가 0 이라 검증이 안 된다.** 콘솔 `cyc 1` / `cyc -1` 을 2초마다
  보내면 화면 내용이 바뀌어 dirty-page 가 계속 생긴다(스트레스 스크립트로 활용).
- **부팅 ~100ms 구간 로그는 USB-JTAG 이 버린다.** 진단값은 static 에 저장해 루프에서 재출력.
- **긴 한글/기호 줄도 유실**된다. 중요 측정값은 짧은 ASCII 한 줄로(`XCONN sda=%d>%d ...`).
- **"에러 0"은 정상의 증거가 아니다.** OLED 미검출이면 flush 를 건너뛰어 에러도 안 난다.
  `present=1` 과 전송 카운터 증가를 함께 볼 것.
- **`#if BOARD_OLED_BITBANG` 밖에서 쓰는 전역은 가드 밖에 선언**할 것.
  가드 안에 두면 `BOARD_OLED_BITBANG=0` 보드(H2)에서 컴파일/링크 에러(실제로 두 번 발생).
- 빌드/플래시 후 **반드시 `error:` 카운트를 확인**할 것. 빌드 실패인데 "플래시 OK"로
  보고한 적 있음.
- **`sdkconfig.defaults.*` 를 고쳐도 안 먹는다.** `build.ps1` 은 보드별 `sdkconfig.<board>`
  를 실제 설정 파일로 쓰고, defaults 는 **최초 생성 때만** 씨앗으로 쓴다. 이미 만들어진
  뒤에는 `sdkconfig.xiao-c6` 를 직접 고쳐야 한다(실제로 한 번 헛빌드했다).
- **리셋 사유는 "그 부팅이 시작된 이유"** 지 "끝난 이유"가 아니다. 헷갈리면 오진한다.

---

## 배경 문서

- `README.md` 「OLED 구동 방식 & 화면 정책」 — 비트뱅 전환 이유, dirty-page, 화면 정책, 진단 로그
- `sim/tools/README_oled_sim.md` — 진단 시뮬레이터 6종 사용법과 한계
  (OLED I2C 3종 + 직렬화·채널잠금·배터리% 3종)
- `doc/CHECKLIST.md` — 기능 구현 현황
- `ISSUE_charge_adc_breaks_oled.md` — 배터리/충전 이슈 4건의 원인·근거·수정·검증 전문
- 커밋 메시지 — 각 변경의 증상→원인→조치가 상세히 기록돼 있다(`git log`)

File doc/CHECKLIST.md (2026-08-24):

# 구현 체크리스트 및 빌드 전 주의사항

## ✅ 구현 완료 항목

| 요구사항 | 파일 | 상태 |
|---|---|---|
| H/W: ESP32-C6 + CC1101 (보드 교체 가능) | `boards/<board>.h`, `cc1101.c` | ✅ |
| RF 447.72 MHz 2-FSK (한국 베네치아), 0.01 MHz 단위 | `somfy_rts.h`, `blind_manager.c` | ✅ |
| Somfy RTS 447 80비트 프로토콜 (RMT + Manchester) | `somfy_rts.c` | ✅ |
| SmartThings Matter 엔드포인트 (C6 8개 / H2 3개) | `app_main.cpp` + `matter_blinds_shim.cpp` | ✅ |
| NVS 블라인드 저장 (C6 8 / H2 3, `BLIND_MAX_COUNT`) | `blind_manager.c` | ✅ |
| **기기별 고유 블라인드 주소** (eFuse MAC → `F0`+등차+ID, 블록 ALL) | `blind_manager.c` `_derive_addresses()` | ✅ |
| **롤링코드 factory-reset 영속** (채널 + 블록 ALL 전용 파티션) | `blind_manager.c` `rollcode` 파티션(`rolling[]`+`all_rolling[]`) | ✅ |
| 블라인드 1개 또는 **블록별 전체(ALL)** 조작 — 채널↑→블록·ALL 자동↑ | `blind_manager_get_targets()` (`all_blocks[]`) | ✅ |
| UP/DOWN/SELECT/PROG/SETUP 버튼 | `button_handler.c` PCF8574 P3~P7 | ✅ |
| 로터리 엔코더 (PCF8574 P0/P1/P2) — full-step(EC11) / half-step(EC05) 분기 | `button_handler.c` + `BOARD_ROT_HALF_STEP`(EC05=그레이코드 LUT 누산) | ✅ |
| **좌/우 버튼 (선택, PCF8575 16핀)** — 메인=블라인드 선택±, 편집화면=자리이동/디지트 커서 | `BOARD_HAS_LR_BUTTONS` + `button_handler.c`(16비트 read) + `somfy_app.c` | ✅ |
| 로터리 클릭 = STOP/MY 커맨드 | `somfy_app.c` `BTN_EVT_ROT_*` 핸들러 | ✅ |
| 버튼 0.1초~15초 조작 범위 | `somfy_app.c` `_clamp_hold()` | ✅ |
| 주파수 0.01 MHz 미세조정 + 저장 | `somfy_app.c` Freq Edit → `blind_manager_set_freq()` | ✅ |
| SmartThings 앱 개별 루틴 설정 | Matter Window Covering Cluster | ✅ |
| Tilt 슬라이더 7단계 step burst | `app_main.cpp` WC delegate + `somfy_rts_send_steps()` | ✅ |
| Lift/Tilt 미러 companion 억제 (400ms) | `app_main.cpp` WC delegate | ✅ |
| 일시정지(Stop) → MY (auto-stop 500ms 가드) | `app_main.cpp` `HandleStopMotion()` | ✅ |
| 진동 wake (X160, IO16) | `button_handler.c` 진동 ISR + duty-cycle | ✅ |
| 보드별 핀맵 config + 빌드 (`-Board`) | `boards/`, `build.ps1` | ✅ |
| 빌드/플래시 로그 logs/ 자동 기록 | `build.ps1` Tee → `logs/<board>-<action>.log` | ✅ |
| 안전망 (Task WDT + crash breadcrumb) | `somfy_app.c`, `button_handler.c` | ✅ |
| **시리얼 진단 콘솔** (tx/sel/cyc/freq/reboot — 버튼 없이 RF 송신·선택·순환·주파수·재부팅 무인 제어) | `app_main.cpp` esp_console + `somfy_app.c` `somfy_app_console_*` | ✅ |
| OLED 일반 화면 (주파수/블라인드/버튼) | `oled_ui.c` `_render_normal()` | ✅ |
| OLED 애니메이션 20fps | `oled_ui.c` FreeRTOS 태스크 50ms | ✅ |
| 버튼 동작 중 5초 애니메이션 | `oled_ui.c` `_render_action()` | ✅ |
| ~~화면보호기~~ **삭제됨**(2026-07) — 대신 유휴 후 패널 OFF | `somfy_config.h` `CFG_SCREEN_OFF_USB_SEC`(USB 5분) / `CFG_SCREEN_OFF_SEC`(배터리 10초) | ✅ |
| 배터리 % 표시 평활 (중앙값 5주기 + EMA) — 송신 순간 전압강하 제거 | `somfy_app.c` `_bat_smooth_mv()` | ✅ |
| USB 없이 배터리 단독 부팅 — CHIP shell 콘솔을 VBUS 있을 때만 시작 | `app_main.cpp` `_usb_vbus_present()` | ✅ |
| 부팅 단계 NVS 기록(전원 끊겨도 보존) + `bd` 콘솔 조회 | `boot_diag.c` / `boot_diag.h` | ✅ |
| 버튼·**진동** 조작 시 즉시 화면 복귀 | `oled_ui_wake()` / `_exit_screensaver()` | ✅ |
| **OLED 비트뱅 I2C**(HW 페리페럴 고착 우회, GPIO 레지스터 직접 접근) | `oled_ui.c` `_bbo_write()` + `BOARD_OLED_BITBANG` | ✅ |
| **dirty-page 전송 감축**(변경된 페이지만 전송, 실측 86% 절감) | `oled_ui.c` `s_shadow`/`_page_dirty()` | ✅ |
| **채널변경 잠금**(RF 버튼·애니메이션 중 SELECT·좌·우 무시) | `somfy_app.c` `_ch_locked()` + `CFG_CH_LOCK_MS` | ✅ |
| **OLED 안정성 계측** `[OLEDMON]`(60초)·`[BBFAIL]` | `oled_ui.c` `g_bbo_tx_cnt`/`g_bbo_fail_cnt` | ✅ |
| 충전률 측정 (5초 주기·8표본) — 직렬화 구멍 수정 후 **재활성** | `somfy_app.c` `TEMP_NO_CHARGE=0` / `_read_bat_mv()` | ✅ |
| OLED 전송 직렬화 — 락을 `_bbo_write()` 로 이동 + **재귀 뮤텍스** | `oled_ui.c` `s_i2c_mutex` · `[OLEDMON] lockTO` | ✅ |
| **OLED 180° 회전 표시** (보드별) | `oled_ui.c` `_fb_flush()` + `BOARD_OLED_ROTATE_180` | ✅ |
| **보드별 디스플레이 규격** (해상도/오프셋/회전/72×40 보정) | `boards/<board>.h` `BOARD_OLED_*` (단일 진실원천) | ✅ |
| **해상도별 렌더러 자동 선택** (보드 무관) | `oled_ui.h` `OLED_RENDER_128X64`/`OLED_RENDER_64X128`/`OLED_RENDER_NATIVE` | ✅ |
| **풀스크린 네이티브 렌더러** (고딕 6×9 폰트 + 7세그 시계) | `oled_ui.c` 128×64 가로 / 64×128 세로 분기 | ✅ |
| **72×40 논리 캔버스 렌더러** (그 외 패널 중앙 배치/블록 스케일) | `oled_ui.c` `_fb_set_pixel()` 폴백 | ✅ |
| 시각 동기화 (Matter SetUTCTime + SNTP 폴백, KST-9) | `somfy_app.c`, Time Sync 클러스터 | ✅ |
| Matter 커미셔닝 (BLE+Thread) | `app_main.cpp` (Matter-over-Thread) | ✅ |
| **펌웨어 업데이트 (Matter OTA over Thread)** | `matter_blinds_shim.cpp` OTA 브리지 + FW Update 메뉴 | ✅ |
| **보드별 OTA 이미지** (브랜드별 PID) | `build.ps1 -Action ota-image` → `dist/*.ota` | ✅ |
| **브랜드별 보드 분리** (gnpe-c6/xiao-c6/esp32-h2) | `boards/<brand>-<soc>.h` | ✅ |
| **XIAO ESP32-C6 핀맵** (LP_I2C MTCK/MTDO, D11 미노출 회피, 온보드 충전) | `boards/xiao-c6.h` (Seeed 핀아웃 검증) | ✅ |
| **ESP32-H2 SuperMini 핀맵** | `boards/esp32-h2.h` (SuperMini 핀아웃 반영) | ✅ 검증 |
| **I2C 버스 공유** (OLED+PCF8574 한 HW I2C — XIAO·H2) | `BOARD_I2C_SHARED` + `button_handler.c` 분기 + `oled_ui_get_i2c_bus()` | ✅ XIAO·H2 검증 |
| **XIAO LP_I2C → 공유 HW I2C 자동 폴백** (부팅 프로브) | `BOARD_I2C_LP_FALLBACK` + `button_handler.c` `_pcf_lp_probe()`/런타임 디스패처 | ✅ 실기 검증(LP 미연결→공유 전환) |
| **ESP32-H2 메모리 최적화** (3채널 · 시각/OTA 메뉴 제외) | `BLIND_MAX_COUNT=3` + `BOARD_DISABLE_TIME`·`BOARD_DISABLE_OTA` | ✅ |
| **페어링 QR 코드** (128×64/64×128 — 좌 PIN + 우 QR 병기) | `oled_ui.c` `_draw_qr_native()` + `espressif/qrcode` | ✅ |
| **Matter Vendor/Product 이름** (`NLB` / `Somfy RTS Thread`) | `CHIPProjectConfig.h` | ✅ |
| SmartThings에서 개별 제어 | Matter 독립 엔드포인트 (C6 = 8 / **H2 = 3**) | ✅ |
| VSCode ESP-IDF v5.4.x 빌드 | `build.ps1`, `.vscode/tasks.json` | ✅ |
| **KiCad 10 4종 변형** (base/_y/_v2/_h2) — 구 _v·_h 삭제 | `kicad/` 폴더 | ✅ |
| **거버 패키지 ZIP + MANIFEST** | `kicad/gerber/` | ✅ |
| **PCB 0 ERROR DRC** | `_electrical_check.py` 0 issues | ✅ |
| 빌드 성공 (경고 없음) | `somfy_blinds.bin` ≈1.7 MB | ✅ |

### 배터리 변형 (`_v2` / `_h2`)

| 요구사항 | 파일 | 상태 |
|---|---|---|
| 851640 600 mAh LiPo (PCM 내장) + JST PH | `kicad/_add_battery.py` BAT1 | ✅ |
| MCP73831 단일 셀 충전 IC (300 mA) | `kicad/_add_battery.py` U4 | ✅ |
| SS14 Schottky 전원경로 | `kicad/_add_battery.py` D1 | ✅ |
| 1분 무입력 light sleep ~~(~750 µA)~~ | `somfy_app.c` `_enter_sleep()` | ✅ 아래 ★ (2026-08-25 실측 완료) |
| 충전/USB 감지 — GNPE: CHG_STAT(IO3 active-LOW) · XIAO/H2: VBUS 분압(active-HIGH) | `button_handler.c` `btn_handler_is_charging()` (`BOARD_CHG_STAT_ACTIVE_HIGH`) | ✅ |
| 배터리 표시: **실측 %**(BAT 분압 ADC) — H2·xiao-c6 모두 `BOARD_BAT_SWAPPED=0`. ~~구 기판의 BAT_ADC↔CHG_STAT 핀 swap(=1, `USB`/`BAT`/`LOW` 상태 표시)~~ 은 배선 개선판에서 해소됐다 | `somfy_app.c` `_read_bat_mv()` / `_bat_mv_to_pct()` | ✅ |
| 충전 중 sleep 차단 + 1분 OLED 애니메이션 | `somfy_app.c` + `oled_ui_show_charging()` | ✅ |

> ★ **`~750 µA` 는 설계 목표였고 그 값으로 실측된 적은 없다.** 다만 2026-08-25 에
> **두 보드 모두 light sleep 96%대**에 도달했다.
>
> | | XIAO-C6 | ESP32-H2 |
> |---|---|---|
> | 잠 | **96.2 %** | **96.6 %** |
> | 깨어남 | **23.7 회/초** | **33.2 회/초** |
> | 방전 | **8.7 mV/시간** (700 mAh 로 약 5일) | — |
> | 깨우기 | LP 코어 눌림 래치 + ULP 깨움 | PCF8574 `~INT` 레벨 트리거 |
>
> 여기까지 온 경로(전부 **계측**으로 찾았다):
>
> | 발견 | 조치 | 효과 |
> |---|---|---|
> | `bt`·`rmt_0_0` PM 락 100% 점유(2026-08-15, 콘솔 `pm`) | `USE_BLE_ONLY_FOR_COMMISSIONING=y` / RMT 를 burst 동안만 | light sleep 진입 자체가 가능해짐 |
> | ★그 수정이 **C6 오버레이에만** 적용됨(2026-08-24) | `h2_thread`·`c6_thread` 도 `y` | H2 **0.0 % → 88.8 %**, free +29.2 KB |
> | 20 ms `button_timer` 가 깨어남의 78 %(콘솔 `tmr`) | 쓰지도 않던 `espressif/button` 제거 | C6 깨어있는 시간 **11.3 % → 3.6 %** |
> | H2 만 113.9 회/초 — `I2C_0` 락 748,352회 | PCF `~INT` 레벨 트리거 ISR | H2 **33.2 회/초, 96.6 %** |
>
> **옛 측정(#22 47.4 mA / #32 52.7 mA)은 전부 PM 락에 갇힌 상태의 값**이므로
> 현재와 비교하지 말 것. 그때 ①(tick)·③(LP 코어)이 눈금에 안 잡힌 이유도 이것이다.
> 자세한 근거·측정법은 `HANDOFF.md` 의 「절전 측정 현황」.

### Sandwich 변형 (`_v2` / `_h2`)

| 요구사항 | 파일 | 상태 |
|---|---|---|
| 2-board 분리 (BOTTOM 메인 + TOP UI) | KiCad PCB 양면 + V-cut | ✅ |
| BTB1-4 board-to-board (10-pin × 2 pair) | `_create_v2_h2.py` BTB symbols | ✅ |
| BREAKAWAY_TAB (V-cut 함께 제조) | PCB 풋프린트 | ✅ |
| **VS1 진동 센서** (JYX-1210-X160, 1210 SMD) | `_add_vibration2.py` VS1 | ✅ |
| **진동 → IO16 GPIO 직결** (light sleep wake) | `boards/gnpe-c6.h` `BOARD_PIN_VIBE=16` | ✅ |
| **진동 wake** (IO16 HIGH-level, duty-cycle 검출) | `button_handler.c` 진동 ISR + 30폴 윈도우 | ✅ |
| **지속 진동 5초 holdoff** | `somfy_app.c` `VIBRATION_HOLD_MS=5000` | ✅ |

---

## ⚠️ 빌드 전 필수 확인사항

### 1. PCF8574 I2C 주소 확인

PCF8574의 A0/A1/A2 핀이 모두 GND에 연결되어 있어야 I2C 주소 `0x20`이 됩니다.

```
PCF8574 핀    연결
──────────    ────
A0 (Pin1)  → GND  (주소 bit0 = 0)
A1 (Pin2)  → GND  (주소 bit1 = 0)
A2 (Pin3)  → GND  (주소 bit2 = 0)
결과 I2C 주소: 0x20
```

다른 주소 필요 시 `button_handler.h`의 `PCF8574_I2C_ADDR` 수정.

### 2. I2C 버스 공유 (OLED + PCF8574)

OLED(SSD1315)와 PCF8574가 동일 I2C 버스(IO18/IO19)를 공유합니다.
`button_handler.c`의 I2C 뮤텍스(`s_i2c_mutex`)가 충돌을 방지합니다.

> `btn_handler_init()`은 반드시 `oled_ui_init()` **이후**에 호출해야 합니다.
> (I2C 버스가 OLED 초기화에서 먼저 열림)

### 3. COM 포트 확인

`build.ps1`의 기본 포트는 `COM3`입니다. 실제 포트로 변경:

```powershell
.\build.ps1 -Action flash -Port COM5   # 장치 관리자에서 확인
```

### 4. PowerShell만 사용 (Git Bash 사용 불가)

```
⚠ Git Bash에서 idf.py 실행 시 MSYSTEM=MINGW64 충돌로 빌드 실패
   반드시 PowerShell 또는 CMD에서 build.ps1 실행
```

### 5. 디스플레이 규격 / 해상도별 렌더러

디스플레이는 **보드별 `BOARD_OLED_*`** 가 단일 진실원천이고, 렌더러는 **해상도로
자동 선택**된다(`oled_ui.h` 의 `OLED_RENDER_*`):

| 해상도 | 렌더러 | 예 |
|---|---|---|
| **128×64 (가로)** | 풀스크린 네이티브 (고딕 6×9 + 7세그) | XIAO 0.96″ SSD1306 |
| **64×128 (세로)** | 풀스크린 네이티브 (세로 적층) | SH1107 계열 세로 패널 |
| **그 외** | 72×40 논리 캔버스 (중앙 배치) | GNPE 0.42″ SSD1315 |

- 프레임버퍼는 **물리 패널 크기**로 잡힌다(72×40=360 B, 128×64=1024 B …).
- GNPE SSD1315(72×40)는 SSD1306(128×64)과 해상도가 달라 **컬럼 오프셋
  `BOARD_OLED_COL_OFFSET=28`**(+ `sdkconfig` `CONFIG_OFFSETX=28`) + 72×40 보정 필요.
- 다른 규격 패널로 바꾸려면 `boards/<board>.h` 의 `BOARD_OLED_*` 만 수정(코드 무수정).

### 6. ESP_MATTER_DEVICE_PATH

`build.ps1`에서 자동 설정됩니다:
```
ESP_MATTER_DEVICE_PATH = esp-matter\device_hal\device\esp32c6_devkit_c
```

---

## 🔧 알려진 제한사항

### Matter 페어링 코드 (기기 고유 — eFuse 산출)
- 128×64 / 64×128 패널 = QR + PIN, 72×40 = PIN(8자리) 텍스트 표시
- discriminator/passcode 를 **eFuse MAC 에서 결정적 산출**(`efuse_commissionable.cpp` custom CommissionableDataProvider) → **기기마다 다른 코드**, fctry 플래시 없이 자동 고유. 여러 대 동시 페어링도 충돌 없음
- (선택) `factory_nvs_gen.py` 로 fctry 에 고정 코드 지정도 가능

### 네트워크 (Matter over Thread)
- v3.0+ WiFi SoftAP 프로비저닝 폐기 → **Matter over Thread (802.15.4)**.
- Thread Border Router 필요(SmartThings Hub v3+, Apple TV 4K, Nest Hub 2nd 등).
- 커미셔닝은 BLE + Thread. OLED 에 8자리 PIN 표시.

### Somfy RTS 주파수
- 기본 register 447.72 MHz(2-FSK) → on-air ~447.678 MHz(정품 ±3 kHz).
- 편집 범위 447.20~447.79 MHz, 0.01 단위(설정 메뉴 → Freq Edit).
- 편집값은 NVS 저장 + **재부팅 후 유지** — 부팅 클램프가 편집 범위 밖 구버전/손상값만 기본으로 보정(`_ensure_blinds`).

### 블라인드 주소 & Rolling Code
- **주소**: ESP32 eFuse 팩토리 MAC 에서 산출(기기별 고유, OTA·reset 불변).
  주소를 바꾼 기기(구 펌웨어 → 신 펌웨어)는 모터에 PROG 재등록 필요.
- **롤링코드 영속**: 전용 `rollcode` 파티션 → Matter factory reset 후에도 보존.
  전체 `erase-flash` 시에만 리셋 → 재페어링(아래) 필요.
- 재페어링 절차: ① 기존 Somfy 리모컨 PROG 6초 → ② ESP32 PROG 단클릭.

### OTA 업데이트 (Matter over Thread)
- 파티션: **듀얼 OTA**(`ota_0`/`ota_1` 각 0x1E0000) + `otadata`. (구 "factory 단일"
  설명은 오래된 것 — 이미 듀얼 OTA.)
- `rollcode` 파티션 추가(0x3E6000, 16KB) — 롤링코드 영속.
- 보드별 PID 로 OTA 이미지 매칭: `build.ps1 -Action ota-image`. 상세: `doc/OTA.md`.

---

## 📐 메모리 현황 (현행)

| 항목 | 값 |
|---|-----|
| 바이너리 크기 | ≈0x1A6800 (1.65 MB) |
| ota_0 / ota_1 | 각 0x1E0000 (1.875 MB) — 12% 여유 |
| otadata | 0x2000 |
| nvs 파티션 | 0xC000 (48 KB) |
| fctry 파티션 | 0x6000 (Matter factory NVS) |
| **rollcode 파티션** | 0x4000 (16 KB, 롤링코드 영속) |
| Flash 총 크기 | 4 MB |

---

## 🗂 소스 파일 구조

```
main/
├── boards/             ← 보드별 핀맵 (board_select.h + <board>.h)
├── app_main.cpp        ← Matter 코어/노드/엔드포인트/WC delegate/OpenThread
├── app_driver.cpp      ← Matter attribute/identify 글루
├── matter_blinds_shim.cpp/h ← matter_blinds_* C API (상태조회/재커미셔닝)
├── somfy_app.c         ← 앱 메인: OLED/버튼/메뉴/시계/절전/안전망
├── cc1101.c/h          ← CC1101 SPI 드라이버 (핀은 boards/ 에서 파생)
├── somfy_rts.c/h       ← Somfy RTS 447 프레임 생성/송신 (RMT)
├── blind_manager.c/h   ← 블라인드 NVS 저장/로드, 선택 관리
├── oled_ui.c/h         ← SSD1306 드라이버 래퍼, 화면 상태 머신
├── button_handler.c/h  ← PCF8574 버튼/로터리 + 진동 ISR
├── thread_provision.c/h ← Thread 네트워크 부착
├── somfy_config.h      ← 설정(BOARD_PIN_* 참조)/타임존/주파수
└── gen_build_epoch.cmake ← 빌드시각 헤더 생성
```

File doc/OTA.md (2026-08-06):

# 펌웨어 업데이트 — Matter OTA over Thread

이 디바이스는 **Thread 위 Matter OTA** 로 무선 펌웨어 업데이트를 받는다.
WiFi·USB 불필요(USB 는 개발용 플래시로만). 설정 메뉴 **"FW Update"** 에서 현재
버전·진행 상태를 보고 수동 업데이트 확인을 트리거할 수 있다.

## 동작 개요

```
[빌드] somfy_blinds.bin (버전 N+1)
   │  image_tool.py 로 Matter OTA 이미지 생성 (.ota)
   ▼
[OTA Provider]  ← chip-tool / ota-provider-app / 허브
   │  AnnounceOTAProvider  또는  디바이스의 수동 QueryImage
   ▼
[디바이스 OTA Requestor]  버전 비교(N+1 > N) → BDX 다운로드 → ota_1 기록 → 재부팅
```

- 디바이스: **듀얼 OTA 파티션**(`ota_0`/`ota_1` 각 1.875 MB) + `CONFIG_ENABLE_OTA_REQUESTOR=y`.
- 현재 보고 버전: `CONFIG_DEVICE_SOFTWARE_VERSION_NUMBER`(= **35**, `sdkconfig`/
  `sdkconfig.defaults`). OTA 이미지는 반드시 **이보다 큰** SoftwareVersion 이어야
  Provider 가 "업데이트 있음" 으로 응답한다.
- 암호화 OTA 비활성(`CONFIG_ENABLE_ENCRYPTED_OTA` 미설정) → **평문 .ota 이미지**.

## 1. 새 펌웨어 빌드 (버전 올리기)

업데이트를 내보내려면 **버전을 반드시 증가**시킨다 (현재 35 → 36).

| 위치 | 항목 | 예 (35 → 36) |
|---|---|---|
| `CMakeLists.txt` | `PROJECT_VER` / `PROJECT_VER_NUMBER` | "3.6" / 36 |
| `sdkconfig` + `sdkconfig.defaults` | `CONFIG_DEVICE_SOFTWARE_VERSION_NUMBER` | 36 |

```powershell
# 버전 수정 후
./build.ps1 -Board gnpe-c6 -Action build
# 산출물: build/somfy_blinds.bin  (SoftwareVersion = 36)
```

> ⚠️ `DEVICE_SOFTWARE_VERSION_NUMBER` 와 `PROJECT_VER_NUMBER` 를 함께 올릴 것.
> 전자는 OTA 비교 기준, 후자는 OLED·`esp_app_desc` 표시 버전.
>
> 🔢 `.ota` 파일명·SoftwareVersionString 의 VERSION 은 **4자리 zero-pad**(예 36 →
> `v0036` / `0036+…`). 숫자 비교용 `vn`(=`DEVICE_SOFTWARE_VERSION_NUMBER`)은 원본
> 값 그대로라 OTA 비교에는 영향 없다.

## 2. Matter OTA 이미지 생성 (.ota) — 보드별

★ **보드(C6/H2)마다 SoC·바이너리가 다르므로 OTA 이미지도 보드별로 따로
만들어야 한다.** 잘못된 보드 이미지를 받지 않도록 **보드별 고유 Product ID** 로
구분한다 (Matter Provider 가 PID 로 매칭).

| 보드 | 브랜드/제품 | SoC | Product ID | sdkconfig |
|---|---|---|---|---|
| `gnpe-c6` | GNPE ESP32-C6-0.42 (검증) | esp32c6 | **0x8000** | `sdkconfig` / `.c6_thread` |
| `xiao-c6` | Seeed XIAO ESP32-C6 (검증) | esp32c6 | **0x8003** | `.c6_thread` + `.xiao_c6` 오버레이 |
| `esp32-h2` | ESP32-H2 SuperMini (검증, I2C 공유) | esp32h2 | **0x8001** | `.h2_thread` |

(VendorID 는 공통 0xFFF1.)

> ★★ **같은 SoC·다른 브랜드 주의** (`gnpe-c6` vs `xiao-c6`): 둘 다 esp32c6 라
> **chip-ID 안전망이 둘을 구분하지 못한다**(이미지가 칩에선 부팅됨). 핀맵만
> 달라 잘못 적용되면 CC1101/버튼이 엉뚱한 GPIO 에 붙어 오동작한다. 따라서
> **Product ID(0x8000 vs 0x8003)가 유일한 보드 식별자** — `.ota` 생성 시
> 반드시 대상 브랜드 PID 와 일치시킬 것. `build.ps1 -Action ota-image` 는
> 보드 sdkconfig 의 PID 를 자동 사용하므로 안전하다.

### build.ps1 로 자동 생성 (권장)

`-Action ota-image` 가 빌드된 `.bin`, **그 보드 sdkconfig 의 VID/PID/버전**,
**`boards/<board>.h` 의 HW 변형(PCF·EC 플래그 + OLED 해상도·회전)**을 읽어
`dist/somfy_blinds_<board>_<pcf>_<enc>_<oled>_v<NNNN>.ota` 를 만든다
(`<oled>`=`<W>x<H>r<0|180>[m]`, `m`=좌우반전, VERSION 4자리) — PID·변형 자동 반영.

```powershell
./build.ps1 -Board gnpe-c6 -Action build        # 버전 올린 뒤 빌드
./build.ps1 -Board gnpe-c6 -Action ota-image     # → dist/somfy_blinds_gnpe-c6_8574_ec11_72x40r180_v0036.ota (PID 0x8000)

./build.ps1 -Board xiao-c6 -Action build
./build.ps1 -Board xiao-c6 -Action ota-image     # → dist/somfy_blinds_xiao-c6_8574_ec05_128x64r0_v0036.ota (PID 0x8003)
```

### 수동 (CHIP 도구 직접)

```bash
python connectedhomeip/src/app/ota_image_tool.py create \
  -v 0xFFF1 -p 0x8000 \                        # ← PID 는 대상 보드 값 (C6=8000 H2=8001)
  -vn 36 -vs "0036+8574.ec11.72x40r180" \      # ← vs=<NNNN>+<pcf>.<enc>.<oled> (VERSION 4자리)
  -da sha256 \
  build/somfy_blinds.bin  dist/somfy_blinds_gnpe-c6_8574_ec11_72x40r180_v0036.ota
```

| 옵션 | 의미 |
|---|---|
| `-v` / `-p` | Vendor / **Product ID (대상 보드값과 일치 필수)** |
| `-vn` | SoftwareVersion **숫자**(비교 기준, 디바이스 현재값보다 커야 함, 예 36) — 파일명/vs 는 4자리 표기 |
| `-vs` | SoftwareVersion **문자열** — `<NNNN>+<pcf>.<enc>.<oled>` 로 HW 변형 태그 부착(식별용) |
| `-da` | digest 알고리즘 (sha256) |

> 암호화 OTA 를 쓰려면 `CONFIG_ENABLE_ENCRYPTED_OTA=y` + 키 지정 필요. 현재
> 프로젝트는 평문이므로 위 명령 그대로.

### 보드 안전망 — chip-ID 검증 (이중 방어)

설령 잘못된 보드 이미지가 전달돼도, **ESP-IDF 부트로더가 이미지 헤더의 chip_id
(esp32c6/esp32h2)를 실행 칩과 대조**해 불일치면 부팅을 거부하고 이전
슬롯으로 롤백한다.

| 경우 | 1차 PID 매칭 | 2차 chip-ID |
|---|---|---|
| 다른 SoC (c6 ↔ h2) | 막음 | **추가로 막음**(부팅 거부+롤백) |
| 같은 SoC·다른 브랜드 (`gnpe-c6` ↔ `xiao-c6`) | 막음 | **구분 못 함**(둘 다 esp32c6) |

→ 같은 SoC 브랜드 구분은 **PID 가 유일 방어선**이므로 보드별 PID 분리가 필수.

### 하드웨어 변형(variant) 구분 — PCF8574/8575 · EC11/EC05 · OLED

PID 는 **보드(브랜드)** 까지만 구분한다. 같은 보드라도 주변장치 빌드 변형이
다르면 펌웨어가 호환되지 않는다:

- **PCF8574(8핀) ↔ PCF8575(16핀)** — 버튼 read/write 폭이 1↔2 byte 로 다르다
  (`BOARD_HAS_LR_BUTTONS`). 잘못 받으면 좌/우 버튼 미동작·입력 오독.
- **EC11(full-step) ↔ EC05(half-step)** — 로터리 디코더가 다르다
  (`BOARD_ROT_HALF_STEP`). 잘못 받으면 한쪽 회전이 안 먹거나 방향이 뒤집힌다.
- **OLED 해상도(72x40 · 128x64 · 64x128) + 회전(0°·180°) + 좌우반전** — 렌더러·표시
  방향이 다르다 (`BOARD_OLED_WIDTH×HEIGHT` · `BOARD_OLED_ROTATE_180` · `BOARD_OLED_FLIP_X`).
  잘못 받으면 화면이 깨지거나 상하/좌우 반전된다.

변형 태그는 **`<pcf>.<enc>.<oled>`** 형식이다(예 `8574.ec05.128x64r0`).
PCF·EC 는 2비트 코드로도 인코딩한다(`board_select.h` `BOARD_HW_VARIANT_*`):

| 코드 | PCF | 엔코더 | `HAS_LR_BUTTONS` | `ROT_HALF_STEP` | PCF·EC 태그 |
|---|---|---|---|---|---|
| 0 | PCF8574 | EC11 | 0 | 0 | `8574.ec11` (GNPE·H2 기본) |
| 1 | PCF8575 | EC11 | 1 | 0 | `8575.ec11` |
| 2 | PCF8574 | EC05 | 0 | 1 | `8574.ec05` (**XIAO**) |
| 3 | PCF8575 | EC05 | 1 | 1 | `8575.ec05` |

> OLED 는 위 코드와 **직교(orthogonal)** 축이라 코드에 넣지 않고 해상도+회전+반전 토큰
> `<W>x<H>r<0|180>[m]`(`BOARD_HW_OLED_STR`, `m`=좌우반전 `BOARD_OLED_FLIP_X`)로 태그 끝에
> 붙인다 — 예 코드2 + 128x64r0 → `8574.ec05.128x64r0`. 현재: **GNPE `72x40r180`**,
> H2 `72x40r0`, XIAO `128x64r0`. 회전·반전 4종 토큰: `r0` 정방향 / `r180` 180° /
> `r0m` 좌우반전 / `r180m` 상하반전 (GNPE/H2 는 같은 72×40 라도 토큰이 갈린다 — PID 와 별개 2차 표식).

> ⚠️ **Matter OTA 는 VID/PID + SoftwareVersion(숫자)만 매칭** → 같은 PID·버전이면
> 변형을 가리지 못한다. 따라서 변형은 **이미지 식별자**로 실어 운영자가 맞는
> 파일을 서빙하게 한다(프로토콜이 자동 차단하지는 않음):
>
> - **`.ota` 파일명**: `somfy_blinds_<board>_<pcf>_<enc>_<oled>_v<NNNN>.ota`
>   (예 `somfy_blinds_xiao-c6_8574_ec05_128x64r0_v0035.ota`) — 운영자 선택 시 1차 방어선.
> - **SoftwareVersionString**(`-vs`): `<NNNN>+<pcf>.<enc>.<oled>`
>   (예 `0035+8574.ec05.128x64r0`) — Provider/허브 로그·이미지 헤더에 남는 식별 문자열.
> - **인코딩 단일 진실원천**: `board_select.h` 의 `BOARD_HW_VARIANT_*` 매크로.
>   `build.ps1 ota-image` 가 같은 규칙으로 `boards/<board>.h` 플래그를 읽어
>   파일명·`vs` 를 만든다 — **OTA 식별은 런타임이 아닌 빌드/패키징 책임**이라
>   펌웨어 동작/바이너리는 바뀌지 않는다(GNPE 코드 불변 검증 완료).

> 🖥️ **왜 화면 자기표시는 안 두나**: FW Update 화면은 72×40 논리 캔버스(128×64
> 패널에서도 중앙 72px)라 `v3.5 8574.ec05` 가 한 줄에 안 들어가 **ec05/ec11 구분
> 글자가 잘린다**. 디바이스측 식별이 필요하면 부팅 시 시리얼 로그로
> `BOARD_HW_VARIANT_STR` 를 남기는 방식이 가볍다(추후).

> ❓ **왜 자동감지·자동롤백이 아닌가**: EC11/EC05 는 기계적 디텐트만 달라 전기적
> 으로 구분 불가(사용자가 돌려봐야 앎), PCF8574/8575 도 0x20 을 공유해 신뢰성
> 있는 자동감지가 어렵다. 잘못된 자동롤백은 부팅 루프 위험 → **식별자 + 운영자
> 확인**을 구분 수단으로 둔다.

> 🔒 **하드 차단이 필요하면**: 변형마다 **별도 Product ID** 를 할당하면 Matter 가
> 프로토콜 레벨에서 막는다(대신 변형마다 커미셔닝 정체성·인증서가 갈라져 무겁다).
> 기본 권장은 위 파일명/vs 태그 방식.

## 3. OTA Provider 실행 + 디바이스에 알림

가장 단순한 검증 경로 = CHIP `ota-provider-app` + `chip-tool`.

```bash
# (a) Provider 가 .ota 파일 서빙
./chip-ota-provider-app --discriminator 22 --secured-device-port 5565 \
    --KVS /tmp/provider.kvs --filepath somfy_blinds_v36.ota

# (b) Provider 를 같은 fabric 에 커미셔닝 (node 0x1)
./chip-tool pairing onnetwork 0x1 20202021

# (c) Provider ACL 에 디바이스 접근 허용
./chip-tool accesscontrol write acl '[{...Operate, subjects:[<deviceNodeId>]...}]' 0x1 0

# (d) 디바이스(node 0xDEV)에 Provider 위치 알림 → 자동 다운로드/적용
./chip-tool otasoftwareupdaterequestor announce-otaprovider 0x1 0 0 0 0xDEV 0
```

- 알림을 받으면 디바이스 OTA Requestor 가 QueryImage → 버전 비교 → BDX 다운로드
  → `ota_1` 기록 → 자동 재부팅 → 새 슬롯 부팅.
- **설정 메뉴 "FW Update"** 화면에서 진행을 볼 수 있다:
  `Idle → Checking.. → DL nn% → Applying.. → (재부팅)`.

> SmartThings/Apple/Google 허브가 OTA Provider 역할을 지원하면 위 chip-tool
> 과정 없이 허브를 통해 배포 가능(허브별 지원 편차 있음).

## 4. 설정 메뉴 "FW Update" 사용법

| 조작 | 동작 |
|---|---|
| 메뉴 → `FW Update` (SET) | 화면 진입 — 현재 버전(`v3.5`) + OTA 상태 표시 |
| **SET** | 수동 업데이트 확인 — 기본 Provider 에 즉시 QueryImage |
| **STOP** | 메뉴 복귀(짧게) / 메인(길게) |

> 🏷️ HW 변형(PCF8574/8575·EC11/EC05)은 화면이 아니라 **`.ota` 파일명·
> SoftwareVersionString** 에 실린다([§하드웨어 변형 구분](#하드웨어-변형variant-구분--pcf85748575--ec11ec05)).
> 디바이스 버전 화면은 PROJECT_VER(`v3.5`)만 표시.

상태 라인: `Idle`(대기) / `Checking..`(질의) / `DL nn%`(다운로드) /
`Applying..`(적용) / `Delayed`(지연) / `N/A`(requestor 미준비).

> "SET=Check" 는 **기본 OTA Provider 가 설정돼 있을 때만** 의미가 있다(없으면
> 무동작). 일반적으로는 Provider/허브가 `AnnounceOTAProvider` 로 밀어주는 흐름.

## 구현 위치 (코드)

| 파일 | 역할 |
|---|---|
| `sdkconfig` / `sdkconfig.defaults` | `CONFIG_DEVICE_SOFTWARE_VERSION_NUMBER=35`, OTA Requestor/듀얼 파티션 |
| `partitions.csv` | `ota_0` / `ota_1` / `otadata` + `fctry`(Matter) + `rollcode`(롤링코드 영속) |
| `main/app_main.cpp` | OTA Requestor 초기화(esp_matter::start 자동 + 암호화 분기) |
| `main/boards/board_select.h` | **HW 변형 인코딩 정의** `BOARD_HW_VARIANT_CODE/_STR/_OLED_STR`(PCF8574/8575·EC11/EC05·OLED 해상도/회전, canonical) + 보드별 PID 분기 |
| `main/matter_blinds_shim.cpp` | C 브리지: `matter_ota_version_str` / `_get_state` / `_trigger_check` |
| `main/somfy_app.c` | 설정 메뉴 `SETUP_FW_UPDATE` + 매-tick 상태 갱신 |
| `main/oled_ui.c` | `_render_fw_update` (버전·상태·진행률) |
| `build.ps1` (`ota-image`) | `.bin`→`.ota` 생성, PID(sdkconfig)+**HW 변형**(board 헤더)을 파일명·`-vs` 에 반영 |

## 알려진 제약

- **앱 크기 vs 슬롯**: 현재 1.65 MB / 슬롯 1.875 MB(여유 ~150 KB). 기능 추가로
  앱이 커지면 슬롯 한계에 주의(초과 시 파티션 재설계 또는 8 MB 플래시 필요).
- **버전 단조 증가 필수**: OTA 이미지 SoftwareVersion 이 현재값 이하이면 무시됨.
- **롤백**: 새 이미지가 부팅 자가검증 실패 시 ESP-IDF app rollback 으로 이전 슬롯
  복귀(앱이 `esp_ota_mark_app_valid_cancel_rollback()` 를 호출해야 확정).
- **롤링코드/블라인드 주소 보존**: OTA 는 앱 슬롯(`ota_0`/`ota_1`)만 갱신 → `rollcode`·
  `nvs`·`fctry` 데이터 파티션은 그대로. OTA 후에도 롤링코드 동기 유지, 재페어링 불필요.
  블라인드 주소는 eFuse MAC 산출이라 펌웨어와 무관하게 항상 동일.

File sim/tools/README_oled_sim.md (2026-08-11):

# OLED I2C · 배터리 표시 진단 시뮬레이터

> 배터리 % 관련은 `bat_pct_display_sim.py`(미연결 판정)·`bat_pct_smooth_sim.py`(표시 평활)
> — 아래 「부록」 참조.

실기 없이(또는 실기 투입 전에) OLED I2C 문제를 좁히기 위한 파이썬 시뮬레이터 4종.
2026-07 "화면이 멈춘다" 문제를 추적하며 만들었고, 실제로 **원인을 좁히고 펌웨어
로직을 사전 검증**하는 데 사용했다.

> 프로젝트 규칙: **빌드/플래시 전에 로직을 파이썬으로 먼저 검증**한다.
> 아래 스크립트는 그 규칙을 OLED I2C 영역에 적용한 것이다.

| 스크립트 | 답하는 질문 |
|---|---|
| `adc_oled_mutex_sim.py` | **직렬화(뮤텍스) 설계가 전송 손상을 막는가** |
| `ch_lock_sim.py` | 채널변경 잠금이 **애니메이션·RF 중 구멍 없이** 막는가 |
| `bat_pct_smooth_sim.py` | 배터리 % **표시 평활**이 튀는 값을 잡는가 ★최신 |
| `oled_i2c_fault_sim.py` | 실측값과 일치하는 **고장모드는 무엇인가** |
| `i2c_bitbang_proto_sim.py` | 비트뱅 프로브 **로직이 맞는가**(플래시 전 검증) |
| `i2c_rise_time_sim.py` | 상승시간으로 **풀업 개수를 구분할 수 있는가** |

전부 `python <파일>` 로 실행하며 인자가 없다. 의존성 없음(표준 라이브러리만).

---

## 0. `adc_oled_mutex_sim.py` — 직렬화 설계 검증 (2026-08-11)

충전률 측정을 되살려도 OLED 가 안 깨지는지를 **플래시 전에** 판정한다.
FreeRTOS 를 흉내낸 초소형 **선점형 스케줄러**로 실제 태스크 우선순위를 재현한다.

```bash
python sim/tools/adc_oled_mutex_sim.py
```

모델의 핵심은 "동시 실행"이 아니라 **선점**이다. ESP32-C6 는 싱글코어라
`somfy_app`(prio 4)이 `oled_ui`(prio 3)를 밀어내고, 비트뱅은 CPU 가 곧 클럭이므로
밀려난 전송은 파형이 중간에 멈춰 SSD1306 을 고착시킨다.

**손상 판정**: 전송 1건이 진행 중일 때 *다른 태스크가 실제로 CPU 를 쓴 시간*을 누적해
20 µs 를 넘으면 손상. 락에 막혀 즉시 블록되는 것은 CPU 를 안 쓰므로 손상이 아니다
— 이 구분이 두 설계를 가르는 지점이다.

**래치 모델**: 손상 1건이 나면 `present=false` 가 되고, 그 뒤 flush 는 바깥 락을 잡기
**전에** return 해 재검출 probe 만 돈다. 이것이 "몇 분 뒤 멈춰서 안 돌아옴"의 정체다.

결과 (8시드 × 10분):

| 구성 | 손상 | 고착 | 고착된 회차 | 최빠른 고착 |
|---|---|---|---|---|
| A. 수정 전 (flush 만 락) | 7 | 7 | **6/8** | **80초** |
| B. 수정 후 (`_bbo_write` 가 락) | **0** | **0** | **0/8** | 없음 |
| C. 보호 없음(참고 상한) | 972 | 968 | 8/8 | 0초 |

배터리 측정은 두 구성 모두 952/952 성공 → **측정 주기(5초)·표본 수(8회)를 줄이지
않아도 기아가 없다**. 줄이면 오히려 `_nobat_track` 의 노이즈 상쇄 가정이 깨진다.

### 이 시뮬레이터를 만들며 잡은 함정 (재사용 시 주의)

- **주기가 정수배면 결과가 거짓이 된다.** 5 s / 50 ms / 10 ms 는 전부 정수배라
  지터 0 이면 기상 위상이 항상 같은 자리에 떨어져 충돌이 **구조적으로 회피**된다
  (첫 실행에서 "손상 0" 이 나온 원인 — 모델 인공물이었다). `JITTER_US` 로 위상을 흔든다.
- **시드 1개로 결론내지 말 것.** 위상 관계가 시드마다 달라 손상 건수가 크게 흔들린다.
  8시드를 합산한다.
- **`for op in gen: yield op` 는 `send()` 를 전달하지 않는다.** 반드시 `yield from`.
  이걸 틀려 락 획득 결과가 `None` 이 되고 unlock 이 실행되지 않아, "배터리 측정
  100 % 실패" 라는 가짜 결과가 나왔었다.
- **동시 기상 시 우선순위 순으로 처리**해야 한다. 낮은 쪽이 먼저 락을 채가면
  거짓 기아가 관측된다.

---

## 1. `oled_i2c_fault_sim.py` — 고장모드 ↔ 실측 대조

KiCad 넷리스트에서 뽑은 회로(풀업 위치·스위치·모듈)를 **저항 네트워크로 모델링**해,
각 고장 가설이 만들어낼 측정값(핀 float / 내부PD / 내부PU 레벨, bit-bang 스캔 결과)을
계산하고 **실기 측정값과 대조**한다. 일치하지 않는 가설을 기계적으로 탈락시킨다.

모델링한 고장모드: 정상 / 스위치 A위치 단락 / 모듈 미연결 / VCC↔GND 역전원 /
SDA↔SCL 교차 / 칩 사망 / SDA GND 단락.

```bash
python sim/tools/oled_i2c_fault_sim.py
```

**핵심 회로 사실**(이 스크립트에 인코딩돼 있음):

- **h4(신 PCB)** : I2C 풀업 4.7K(R8/R9)가 **PCB 에 있다** → 모듈이 없거나 무전원이어도
  버스는 HIGH 로 보인다. "버스가 정상이니 모듈이 연결됐다"고 추론하면 **틀린다**.
- **v4(구 PCB)** : I2C 에 **PCB 풀업이 없다** → 측정된 HIGH 는 곧 **모듈 자체 풀업**이므로
  모듈에 전원이 들어와 있다는 증거가 된다.

이 비대칭이 진단의 핵심이었다. 실측 대조 결과 COM7 은 "모듈 미연결 / SDA↔SCL 교차 /
칩 무응답" 3개로, COM4 는 "SDA 라인 GND 단락" 1개로 좁혀졌다.

## 2. `i2c_bitbang_proto_sim.py` — 비트뱅 프로토콜 검증

`test/somfy_cases/oled_only_test.c` 의 bit-bang 프로브와 **동일한 파형 시퀀스**를
파이썬으로 재현하고, SSD1306 슬레이브 상태머신을 모델링해 ACK 를 검증한다.
플래시하기 전에 로직 오류를 잡는 용도.

```bash
python sim/tools/i2c_bitbang_proto_sim.py
```

검증 항목 3가지:

1. 정상 배선에서 정방향 프로브가 `0x3C` 를 검출하는가
2. 교차 배선에서 정방향 프로브가 무응답인가 (실측과 같은 증상인가)
3. 교차 배선을 **핀을 맞바꾼 프로브**가 검출하는가

★부수 발견: 슬레이브가 ACK 후 SDA 를 놓지 않으면 **이후 전 주소가 거짓 ACK** 된다.
COM4 실측(`전 주소 응답`)과 정확히 같은 패턴이었고, 이 시뮬레이터로 재현해 확인했다.

## 3. `i2c_rise_time_sim.py` — 상승시간 구분력 검토

풀업이 1개일 때와 2개(병렬)일 때 라인 상승시간이 2배 차이 나는 것을 이용해
**모듈 전원 인가 여부**를 판별할 수 있는지 계산한다. 버스 용량 50/100/200 pF,
폴링 분해능 12/25 ns 조건에서 구분 가능 여부를 표로 출력한다.

```bash
python sim/tools/i2c_rise_time_sim.py
```

> ⚠ **실기에서는 무효였다.** 계산상으로는 구분 가능하지만, 실제 펌웨어는 폴링에
> `gpio_get_level()`(HAL 함수)을 써서 1회 호출이 상승시간보다 오래 걸린다.
> 측정값이 `SDA=0 SCL=0`(=첫 읽기에 이미 HIGH)으로 나와 분해능이 부족했다.
> 쓰려면 **GPIO 레지스터 직접 읽기**로 폴링 루프를 다시 짜야 한다.
> 기록 보존용으로 남긴다.

---

## 관련 펌웨어 진단 도구

- **`build.ps1 -OledTest`** — OLED 단독 부팅 테스트(`test/somfy_cases/oled_only_test.c`).
  Matter/Thread/BLE/RF/버튼/배터리를 **전혀 초기화하지 않고** OLED 만 구동한다(~100ms 부팅).
  I2CDIAG(핀 pull 특성) → bit-bang 전체 스캔 → 교차배선 재시도 → force-drive 순으로 진단.
- **`[OLEDMON]`** (60초 주기) — 전송/실패 누적, 페이지 보냄/건너뜀, `present`, free heap.
- **`[BBFAIL]`** — 비트뱅 전송 실패(20회마다 1줄).

## 함정 (실제로 당한 것들)

- **로그 인코딩은 캡처 경로마다 다르다.** pyserial 직접 캡처 = **UTF-8**,
  빌드 로그(`logs/*.log`) = **CP949**. 틀리게 디코드하면 한글 에러가 **0건으로 오독**된다.
  `try utf-8 → except cp949` 로 판별할 것. 이것 때문에 "에러 0, 해결됨"이라고
  잘못 판단한 적이 있다.
- **부팅 ~100ms 구간 로그는 USB-JTAG 이 버린다.** 진단값은 static 에 저장해 두고
  나중에(루프에서) 다시 출력해야 확실히 보인다.
- **긴 한글/기호가 섞인 로그 줄도 유실**된다. 중요한 측정값은 **짧은 ASCII 한 줄**로
  찍을 것(`XCONN sda=%d>%d scl=%d>%d SHORT=%d`).
- "에러가 0건"은 **정상의 증거가 아니다.** OLED 가 미검출이면 flush 자체를 건너뛰어
  에러도 안 난다. `present=1` 과 전송 카운터 증가를 함께 봐야 한다.

---

# 부록 — `bat_pct_display_sim.py` (배터리 % 표시)

"배터리를 안 꽂았는데 **78%** 로 표시된다" 를 고친 로직을 플래시 전에 검증한다.

```bash
python sim/tools/bat_pct_display_sim.py
```

## 왜 하필 78% 인가

배터리를 빼도 충전 IC(MCP73831)가 BAT+ 를 무부하로 **약 3,970 mV** 로 띄운다.
이 값을 OCV-SoC 곡선에 넣으면 정확히 78% 가 나온다:

```
3850mV=60%, 3980mV=80% 구간 보간
60 + 20 × (3970-3850)/(3980-3850) = 78.4% → 78%
```

**전압만으로는 실제 배터리 78% 와 구분이 불가능하다.** 유일한 단서는
"전압이 오르는가"(무배터리 float = 안 오름 / 충전 중인 셀 = 오름)이고,
이 판정은 5분 창이 차야 나온다 → 그전 5분간 78% 가 보였다.

## 수정 — 애매할 때만 숨긴다

```
ambiguous = (3940 <= mv <= 4010) and USB연결
표시 = "--%"                if (첫 판정 전) and ambiguous
       0%                   elif 미연결 판정
       _bat_mv_to_pct(mv)   else
```

float 창 **밖**이면 충전 IC 가 그 값을 만들 수 없어 배터리 존재가 전압만으로
확정되므로 **대기 없이 즉시** % 를 보여준다. 실제로 배터리를 꽂은 사용자는
거의 기다리지 않고, 배터리가 없는 경우만 5분 뒤 0% 로 확정된다.

| 시나리오 | 0분 | 3분 | 10분 |
|---|---|---|---|
| 무배터리 + USB (문제 상황) | 78% → **--%** | 78% → **--%** | 0% → 0% |
| 실배터리 78% + USB (충전중) | 77% → **--%** | 78% → **--%** | 80% → 80% |
| 실배터리 40% + USB | 40% → **40%** | 41% → 41% | 43% → 43% |
| 배터리 구동(USB 없음) | 78% → **78%** | 78% → 78% | 78% → 78% |

(각 칸은 `수정전 → 수정후`)

## ★창(5분)을 줄이면 안 된다

충전 상승률이 ≈9.3 mV/5분 이라, 창이 짧으면 전반/후반 평균차가 판정 문턱(4 mV)에
못 미쳐 **진짜 충전 중인 배터리를 "미연결"로 오판**해 0% 로 표시한다.

| 창 | 전반/후반 평균차 | 문턱 4mV 대비 |
|---|---|---|
| 1분 | 0.9 mV | 오판 |
| 2분 | 1.9 mV | 오판 |
| 3분 | 2.8 mV | **오판** |
| **5분** | **4.7 mV** | **안전** |

→ "첫 창만 3분으로 단축" 은 안전해 보였지만 실제로는 위험하다. 이 표가 그 근거다.

---

# 부록 2 — `bat_pct_smooth_sim.py` (배터리 % 표시 평활)

배터리 구동에서 % 가 81→82→**74**→84→81 로 튀는 것을 잡는 후처리를 검증한다.

```bash
python sim/tools/bat_pct_smooth_sim.py
```

**왜 배터리에서만 생기나**: USB 는 레일이 단단해 전압이 거의 안 변한다. 배터리는 BLE
광고·RF 송신 순간 **실제로** 떨어진다. 5초 주기 측정이 그 순간에 걸리면 한 점이 크게
낮게 찍히고, OCV 곡선상 이 구간은 **1 % ≈ 10 mV** 라 100 mV 로 10 %p 가 움직인다.

**설계**: 측정은 그대로 두고(주기 5초·8표본 — `_nobat_track` 가정 보존) 표시 경로에만
**중앙값 5주기 + EMA(α=1/4)** 를 적용한다. 평균이 아니라 중앙값을 쓰는 이유는 평균이
-100 mV 이상치 하나에 통째로 끌려가기 때문이다.

| 지표 | 원본 | 평활 |
|---|---|---|
| 진폭 | 19 %p | **9 %p** |
| 주기간 평균 변동 | 4.09 %p | **0.38 %p** |
| 최저값(송신 강하 노출) | 66 % | **75 %** |
| 방전 추종 지연 | — | 2 %p 이내 |

### ★이 시뮬레이터가 잡아낸 실제 버그

C 의 정수 나눗셈은 **0 쪽으로 절단**한다. 1 mV 단위로 `ema += (med-ema)/4` 를 쓰면
차이가 1~3 mV 일 때 몫이 0 이 되어 **EMA 가 영영 안 움직인다**(고착). 파이썬의 `//` 는
내림이라 그냥 옮겼으면 못 봤을 것이다 → 시뮬레이터에서 `int()` 로 C 절단을 흉내내
검출했고, 펌웨어는 **1/16 mV 단위 누적**으로 해결했다.

추종성 검사(평활이 값을 붙잡아두지 않는가)를 함께 넣은 것도 이 때문이다.

---

# 부록 3 — `ch_lock_sim.py` (채널변경 잠금)

"버튼 눌러 애니메이션 재생 중인데 좌/우 채널변경이 먹는다"를 잡는다.
누름 시간별로 **잠금 / 애니메이션 / RF 송신** 타임라인을 그려 구멍을 찾는다.

```bash
python sim/tools/ch_lock_sim.py
```

수정 전 발견된 구멍(잠금은 풀렸는데 아직 RF 송신 중):

| 누름 | 열려 있던 구간 |
|---|---|
| 2초 | 2.3초 |
| **3초** | **4.2초** |
| 5초 | 4.0초 |

원인 두 가지 — ① `action_start_ms` 가 **누른 시각**이라 2.5초보다 길게 누르면 떼는 순간
애니메이션 상태가 즉시 해제된다(블라인드 조작은 길게 누르는 게 정상) ② `_ch_locked()`
가 실제 RF 송신 진행 여부를 안 봤다. 수정 후 전 구간 구멍 0.

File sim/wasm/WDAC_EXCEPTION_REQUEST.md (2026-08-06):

# WDAC(Device Guard) 예외 요청 — Emscripten(emsdk) WASM 빌드용

## 배경
- 펌웨어(`main/oled_ui.c`)의 OLED 렌더링을 **웹 시뮬레이터**에서 그대로 실행해 테스트하기 위해
  Emscripten(emsdk)으로 WASM 빌드가 필요합니다.
- 이 PC는 **Device Guard / WDAC(Windows Defender Application Control)** 가 **Enforced(=2)** 모드입니다.
  - 확인: `Get-CimInstance Win32_DeviceGuard -Namespace root\Microsoft\Windows\DeviceGuard`
    → `CodeIntegrityPolicyEnforcementStatus = 2`
- emsdk의 LLVM 도구(미서명)가 정책에 차단됩니다:
  - 실행 시도 → `blocked by your organization's Device Guard policy` (오류 4551)
- 참고: ESP-IDF(`~/.espressif`)의 컴파일러도 **미서명**이지만 **managed-installer 신뢰**로 통과합니다.
  emsdk는 git clone + python 설치라 그 신뢰 태그가 없어 차단됩니다.

## 요청
아래 LLVM 실행파일(또는 `D:\emsdk\upstream\bin\` 디렉토리)을 코드 무결성 정책에 **신뢰 추가**해 주세요.
빌드에 실제로 필요한 것은 **clang.exe** 와 **wasm-ld.exe** 두 개이며, 보조 도구까지 포함하면 아래 목록입니다.

| 파일 | 경로 | 역할 |
|---|---|---|
| clang.exe | `D:\emsdk\upstream\bin\clang.exe` | C → WASM 컴파일 |
| wasm-ld.exe | `D:\emsdk\upstream\bin\wasm-ld.exe` | WASM 링크 |
| clang++.exe | `D:\emsdk\upstream\bin\clang++.exe` | (보조) |
| lld.exe / llvm-ar.exe / llvm-nm.exe / llvm-objcopy.exe | `D:\emsdk\upstream\bin\` | (보조) |

### SHA256 (해시 규칙용)
```
clang.exe    2DA762F1C18603E35ABC6DE2A8081B5FA5652AE71A93A802DFFA029AED68DD89
wasm-ld.exe  02D242B99FCCFC60E5A8C04F8A489497F848793315E9B06839C4FF74BE463D40
```
> 나머지 파일 해시가 필요하면 `Get-FileHash <path> -Algorithm SHA256` 로 추출 가능합니다.

## 등록 방법 (관리자, 택1)
**A. 경로 규칙 (가장 간단)** — `D:\emsdk\` 하위를 신뢰. WDAC 보충 정책에 FilePath 규칙:
```powershell
# 예시 — 실제 정책 파일/배포는 환경에 맞게
$rules  = New-CIPolicyRule -FilePathRule "D:\emsdk\*"
New-CIPolicy -FilePath .\emsdk_allow.xml -Rules $rules -UserPEs
ConvertFrom-CIPolicy .\emsdk_allow.xml .\emsdk_allow.cip
# .cip 를 코드무결성 보충정책으로 배포(그룹정책/Intune/CITool)
# CITool -up .\emsdk_allow.cip   (Win11 22H2+)
```
**B. 해시 규칙** — 위 SHA256 으로 `New-CIPolicyRule -Hash` (업데이트 시 갱신 필요).

**C. Managed Installer** — emsdk 를 신뢰된 설치자로 재설치(환경에 따라).

## 검증 (예외 등록 후)
```powershell
cmd /c "D:\emsdk\upstream\bin\clang.exe --version"   # 버전이 출력되면 통과
```
그 다음 빌드:
```powershell
D:\dev\workspaces\somfy-blinds-things-by-claude\sim\wasm\build.ps1
# → sim\oled_sim.js (+ .wasm) 생성. web_sim.html 새로고침하면 자동 WASM 모드.
```

## 보안 메모
- emsdk 는 공개 오픈소스(Emscripten/LLVM) 입니다. 자체 서명이 없을 뿐 출처는 명확합니다.
- 경로 규칙(A)은 `D:\emsdk` 전체를 신뢰하므로, 보안상 해시 규칙(B)을 선호하면 위 2개 해시만으로도 빌드가 됩니다(보조 도구가 추가로 막히면 그 해시도 동일 방식으로 추가).

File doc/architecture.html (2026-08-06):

✅ 현행 아키텍처 (v3.x · Matter over Thread) — 3보드(GNPE C6 / XIAO C6 / ESP32-H2) · 빌드타임 변형(PCF·로터리·OLED) · 블록 ALL 주소 · Bridge/composed Matter.
단일 진실원천 → main/boards/<board>.h + board_select.h · 핀맵 → doc/wiring/ · 설치 → SETUP_GUIDE.md · OTA → OTA.md · 개요 → README.md.

# 🪟 Somfy RTS Wood Blind Controller — System Architecture

ESP32-C6 / ESP32-H2 (RISC-V, 802.15.4) + CC1101 (447 MHz 2-FSK) + PCF8574/75 + SSD1306 OLED | SmartThings Matter-over-Thread | ESP-IDF v5.4.1 + esp-matter

## 📐 시스템 레이어

하드웨어

ESP32-C6/H2 SoC
CC1101 RF (447 MHz)
PCF8574/75 I2C 확장
SSD1306 OLED · 로터리 · 진동

드라이버

cc1101.c (SPI + RMT TX)
somfy_rts.c (80비트 프레임)
button_handler.c (PCF 폴링)
oled_ui.c (렌더러 자동선택)

애플리케이션

somfy_app.c (메인 루프·메뉴·RF 큐)
blind_manager.c (주소·롤링·NVS)
thread_provision.c

Matter / Cloud

app_main.cpp (엔드포인트)
matter_blinds_shim.cpp
OpenThread + CHIP
→ SmartThings

## 🧩 보드 매트릭스

속성 | GNPE ESP32-C6-0.42 | Seeed XIAO ESP32-C6 | ESP32-H2 SuperMini
SoC | ESP32-C6 | ESP32-C6 | ESP32-H2
OLED (기본) | 내장 0.42″ 72×40 (180° 회전) | 외부 0.96″ 128×64 (정방향) | 외부 모듈 (128×64 등)
I2C 구성 | 분리 (OLED HW + PCF 비트뱅) | LP_I2C → 공유 HW 자동폴백 | 공유 (OLED+PCF 한 HW I2C)
로터리 (기본) | EC11 (full-step) | EC05 (half-step) | EC11
충전 | MCP73831 외부 600 mAh / 300 mA | 온보드 SGM40567 500 mAh / 120 mA | 온보드 TP4054 400 mAh / 100 mA
Matter PID | 0x8000 | 0x8003 | 0x8001
블라인드 채널 | 8 (2블록) | 8 (2블록) | 3 (1블록)
Matter 구조 | Bridge | Bridge | composed
빌드 | -Board gnpe-c6 | -Board xiao-c6 | -Board esp32-h2
상태 | ✅ 검증 | ✅ 검증 | ✅ 검증

단일 진실원천은 각 boards/<board>.h. 같은 SoC(C6)라도 브랜드마다 핀이 달라 보드 파일을 분리하고, OTA 구분은 칩 ID 가 같아(esp32c6) 브랜드별 PID 로만 한다. 상세 핀맵은 doc/wiring/.

## 🔀 빌드타임 변형 조합 (board_select.h ← build.ps1)

보드 헤더를 안 고치고 한 보드에서 PCF·로터리·OLED 변형을 빌드 시 고른다. 안 주면 보드 기본값(바이너리 동일). build.ps1 가 -D BOARD_OVR_* 로 주입 → board_select.h 가 보드 기본을 덮는다.

옵션 | 값 | 덮는 매크로 | 효과
-Pcf | 8574 / 8575 | BOARD_HAS_LR_BUTTONS | 8575 = 좌/우 버튼(P10/P11) 추가 · read/write 2바이트
-Rotary | ec11 / ec05 | BOARD_ROT_HALF_STEP | ec05 = half-step 그레이코드 LUT 누산 디코더
-Oled | 72x40 / 128x64 / 64x128 | BOARD_OLED_WIDTH/HEIGHT | 해상도 → 렌더러 자동 선택(아래). ※ CONFIG_OFFSETX 동반 조정(72x40=28 / 그외=0)
-Rotate | 0 / 180 / m0 / m180 | OLED_ROTATE_180 + OLED_FLIP_X | 회전 · 좌우반전(m=mirror). sdkconfig 무관, 완전 자동

변형 태그 BOARD_HW_VARIANT_STR = <pcf>.<enc>.<oled> (예 8574.ec05.128x64r0). Matter OTA 는 VID/PID + 버전만 매칭하므로, 변형을 SoftwareVersionString · .ota 파일명에 실어 교차 설치를 막는다(EC11/EC05 · 8574/8575 · OLED 는 전기적 자동감지 불가 → 이미지 식별자로 구분).

### OLED 렌더러 자동 선택 (해상도 기준, 보드 무관)

해상도 | 렌더러 | 비고
128×64 (가로) | 풀스크린 네이티브 | 고딕 6×9 폰트 + 7세그 시계, 가로 배치
64×128 (세로) | 풀스크린 네이티브 | 세로 적층 (SH1107 등)
그 외 (72×40 등) | 72×40 논리 캔버스 | 어떤 패널에도 중앙 배치 / 블록 스케일

oled_ui.c 가 BOARD_OLED_WIDTH×HEIGHT 만 보고 렌더러를 고른다 → 보드는 패널 규격 6개 매크로(BOARD_OLED_*)만 선언하면 디스플레이 교체 가능(코드 수정 불필요).

## ⚙️ 보드별 펌웨어 기능 차이 (ESP32-H2 메모리 제약)

⚠ ESP32-H2 는 가용 RAM ~145 KB — OpenThread FTD + Matter 가 free heap 을 거의 소진한다(BLE 커미셔닝 중 free ~2.5 KB). 그래서 H2 는 기능을 빼서가 아니라 메모리에 맞춰 아래처럼 축소·단순화한다(C6 두 보드는 RAM 여유로 제약 없음).

항목 | GNPE / XIAO (C6) | ESP32-H2 | 매크로
블라인드 채널 | 8 (2블록 · ALL2) | 3 (1블록 · ALL1) | BLIND_MAX_COUNT
Matter 구조 | Bridge (Aggregator + bridged) | composed (root 직속 WC) | BOARD_MATTER_COMPOSED
설정 메뉴 | 6항목 (Time Set · FW Update 포함) | 4항목 (Time/FW 제외) | BOARD_DISABLE_TIME/OTA
시각 동기 · 시계 | SetUTCTime + SNTP + 시계 화면 | 없음 | BOARD_DISABLE_TIME
펌웨어 OTA | Matter OTA over Thread | 없음 | BOARD_DISABLE_OTA
페어링 화면 | PIN (72×40) / PIN+QR (128×64) | PIN + QR (외부 패널) | 해상도 자동
SmartThings 노출 | 블라인드별 독립 타일(스톡 드라이버) | 1카드 3블라인드 (custom Edge driver) | smartthings-driver/
안정 상한 | 8 블라인드 (페어링 시 free ~20 KB 빡빡) | 2 블라인드 (커미셔닝 peak) | RAM

Vendor / Product 이름은 전 보드 공통 NLB / Somfy RTS Thread (CHIPProjectConfig.h).

## 🔑 블록 ALL 주소 체계 & 롤링코드

주소 = F0 · [중간: 채널 등차] · [하위: 보드 ID] (24비트, eFuse 팩토리 MAC → FNV-1a 결정적 산출 · blind_manager.c _derive_addresses):

요소 | 규칙
상위 바이트 | 0xF0 고정 (전 보드 공통)
중간 바이트 (블록 base) | (eFuse_hash >> 8) % 0x27 → 등차 최소항 0~0x26 (carry 없음)
하위 바이트 | eFuse_hash & 0xFF (보드 고유 ID · 블록별 salt (g+1)×0x9E3779B1)
채널 i | base + i × 0x2700 (중간바이트 +0x27 등차)
ALL | base + 4 × 0x2700 (채널 등차의 다음 항)

4채널 = 1블록(채널 4 + 전용 ALL 1). BLIND_BLOCK_COUNT = ceil(채널/4) → H2 1블록(ALL1), C6 2블록(ALL1·ALL2), 9채널 3블록. ALL 명령 시 모든 블록의 ALL 을 차례로 송신, 채널 endpoint 들을 한꺼번에 position 갱신.

롤링코드는 전용 rollcode NVS 파티션에 채널(rolling[]) + 블록 ALL(all_rolling[]) 을 모두 보존 → Matter factory reset 후에도 복원(역행 방지). ALL 은 PROG 등록 절차가 없어(모터 내부 인식) 롤링코드 영속이 특히 중요하다.

🔑 페어링 코드(discriminator/passcode)도 같은 eFuse MAC 에서 산출(efuse_commissionable.cpp, custom CommissionableDataProvider) → 기기마다 다른 QR/PIN, fctry 플래시 불필요. 여러 대 동시 페어링도 BLE discriminator 충돌 없음(실측 disc gnpe 3327 · xiao 4032 · h2 2687). CONFIG_CUSTOM_COMMISSIONABLE_DATA_PROVIDER=y, DAC provider 는 별개 유지.

## 🌐 Matter 엔드포인트 구조

Bridge (C6 — 독립 타일)

EP0 Root (Basic Info: NLB / Somfy RTS Thread · Time Sync)
└ Aggregator
├ Bridged WindowCovering #1 (Blind 1)
├ … #8
→ SmartThings / Apple / Google 기기 8개

composed (H2 — 1기기 다중 EP)

EP0 Root (Basic Info)
├ EP1 WindowCovering (Blind 1)
├ EP2 · EP3
→ Apple / Google 3개 · SmartThings 는 custom driver 로 1카드 3블라인드

WindowCovering features: Lift + Tilt + PositionAware. Lift % ↔ Somfy UP/DOWN, Tilt 슬라이더 → 7단계 step burst, STOP → MY. ALL 에서는 PROG 차단(단일 블라인드 절차).

## 🔌 I2C 버스 구성 (보드별)

보드 | OLED | PCF8574/75 | 방식
GNPE C6 | HW I2C (IO0 / IO1) | 비트뱅 (IO18 / IO19) | 분리 — 서로 다른 핀, 충돌 없음
XIAO C6 | HW I2C (D4/D5 = 22/23) | LP(6/7) → 공유(22/23) | 자동폴백 — 부팅 프로브로 LP/공유 택1
ESP32-H2 | 한 HW I2C 버스 공유 (GP13 / GP14) | | 공유 — OLED + PCF device

공유 버스(XIAO 폴백 · H2)에서 OLED(400k) / PCF(100k) SCL 불일치 시 i2c_master_receive 가 INVALID_STATE 격번 → PCF scl 을 400k 로 통일 + 즉시 재시도(최대 4회)로 흡수. OLED flush ↔ PCF read 는 뮤텍스로 직렬화.

## 💾 파티션 테이블 (4 MB Flash · partitions.csv)

Name | Type | Offset | Size | 용도
esp_secure_cert | 0x3F | 0x0D000 | 0x2000 | DAC 인증서 (암호화)
nvs | nvs | 0x10000 | 0xC000 | 설정 · 블라인드 · Thread/Matter
nvs_keys | nvs_keys | — | 0x1000 | NVS 암호화 키
otadata | ota | — | 0x2000 | OTA 부팅 슬롯 선택
phy_init | phy | — | 0x1000 | RF 캘리브레이션
ota_0 | app | 0x20000 | 0x1E0000 | 앱 슬롯 A (1.875 MB)
ota_1 | app | 0x200000 | 0x1E0000 | 앱 슬롯 B (듀얼 OTA)
fctry | nvs | 0x3E0000 | 0x6000 | 공장 데이터 (페어링 PIN 등)
rollcode | nvs | 0x3E6000 | 0x4000 | 롤링코드 전용 — factory reset 내성

⚠ 전체 erase-flash 는 rollcode 까지 지움 → 재-PROG 필요. Matter factory reset(기본 nvs 만 삭제) · OTA 는 rollcode 보존.

## 🧵 FreeRTOS 태스크

태스크 | 소스 | 역할
somfy_app | somfy_app.c | 메인 루프(100 ms) · 버튼 이벤트 · 설정 메뉴 · RF 큐 push · 화면보호기/절전 · Task WDT
btn_handler | button_handler.c | PCF8574/75 폴링(10 ms) · 로터리 디코더 · 진동/충전 GPIO · ~INT wake
OLED 렌더 | oled_ui.c | 20 fps 애니메이션 · 해상도별 렌더러 · 화면보호기
rf_worker | somfy_app.c | RF 큐에서 job 꺼내 직렬 송신(틸트 코얼레스)
CHIP / OpenThread | esp-matter | Matter 스택 · 802.15.4 SED · 커미셔닝 · OTA

★ 커미셔닝 중에는 OLED/버튼 연속 태스크를 지연 시작(_deferred_task_starter) — 802.15.4 / SRP / CASE 타이밍 보호.

## 🔄 데이터 흐름

### SmartThings → 블라인드

SmartThings 앱

→

Thread Border Router

→

Matter WC delegate
(app_main.cpp)

→

RF 큐 (somfy_app)

→

CC1101 80비트 송신

### 물리 버튼 → 블라인드 + Matter 상태 동기화

PCF 버튼 / 로터리

→

btn_handler 이벤트

→

get_targets
(채널 / 블록 ALL)

→

CC1101 송신 + 롤링 ↑

→

matter position 갱신
(ALL = 채널 팬아웃)

## 🔨 빌드 & 배포 (build.ps1)

액션 | 설명
-Action set-target | 보드별 IDF target + 검증 sdkconfig (.verified.bak 백업)
build | <builddir>/somfy_blinds.bin — 보드별 분리(build / build-xiao-c6 / build-esp32-h2)
flash / monitor | 플래시 / 시리얼 모니터 (네이티브 USB 리셋·재열거 처리)
ota-image | 보드별 Matter OTA .ota 생성 (PID + 변형 태그)
erase | ⚠ 전체 flash 삭제 (rollcode 포함 → 재-PROG)

테스트: test/build_test.ps1 -Mode virtual (프레임 정합성 + ALL 라우팅 가상 검증, CC1101 불필요) / -Mode onair (실제 RF 송신).

Somfy RTS Wood Blind Controller · ESP-IDF v5.4.1 · esp-matter 7706cfbd · esp-idf-ssd1306 554df45 · esp_qrcode 0.2.0 · 현행 v3.x (Matter over Thread)
단일 진실원천: main/boards/<board>.h · board_select.h · partitions.csv · build.ps1. 상세는 README / doc/wiring / doc/OTA. | 구 v1.1 (WiFi · LP_I2C 분리) 스냅샷은 git 히스토리 참조.

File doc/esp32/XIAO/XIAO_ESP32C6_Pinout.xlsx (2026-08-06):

Table 7-2. QFN32 Package Pin Summary
管脚 序号 | 管脚 名称 | 管脚 类型 | 供电 管脚 | 管脚配置 |  | 模拟功能 |  | LP IO MUX 功能 |  | IO MUX 功能 |  |  |  |  |  |  | JTAG | USB | USER LED | LP IO MUX | BOOT
 |  |  |  | 复位时 | 复位后 | 0 | 1 | 0 | 1 | 0 | 类型 | 1 | 类型 | 2 | 类型 |  | GPIO | SDIO | Digital | Analog | IIC
1 | ANT | Analog |  |  |  |  |  |  |  |  |  |  |  |  |  |  | UART | SPI | ALL PWM | ALL I2S
2 | VDDA3P3 | Power
3 | VDDA3P3 | Power
4 | CHIP_PU | Analog |  |  |  |  |  |  |  |  |  |  |  |  |  |  | definition foot | multiplex
5 | VDDPST1 | Power
6 | XTAL_32K_P | IO | VDDPST1 |  |  | XTAL_32K_P | ADC1_CH0 | LP_GPIO0 | LP_UART_DTRN | GPIO0 | I/O/T | GPIO0 | I/O/T |  |  |  | D0 | A0 | GPIO0 | LP_GPIO0 | LP_UART_DTRN
7 | XTAL_32K_N | IO | VDDPST1 |  |  | XTAL_32K_N | ADC1_CH1 | LP_GPIO1 | LP_UART_DSRN | GPIO1 | I/O/T | GPIO1 | I/O/T |  |  |  | D1 | A1 | GPIO1 | LP_GPIO1 | LP_UART_DSRN
8 | GPIO2 | IO | VDDPST1 | IE | IE |  | ADC1_CH2 | LP_GPIO2 | LP_UART_RTSN | GPIO2 | I/O/T | GPIO2 | I/O/T | FSPIQ | I1/O/T |  | D2 | A2 | GPIO2 | LP_GPIO2 | LP_UART_RTSN
9 | GPIO3 | IO | VDDPST1 | IE | IE |  | ADC1_CH3 | LP_GPIO3 | LP_UART_CTSN | GPIO3 | I/O/T | GPIO3 | I/O/T |  |  |  | D11 | A3 | GPIO3 | LP_GPIO3 | LP_UART_CTSN
10 | MTMS | IO | VDDPST1 | IE | IE |  | ADC1_CH4 | LP_GPIO4 | LP_UART_RXD | MTMS | I1 | GPIO4 | I/O/T | FSPIHD | I1/O/T |  | MTMS | A4 | GPIO4 | LP_GPIO4 | LP_UART_RXD
11 | MTDI | IO | VDDPST1 | IE | IE |  | ADC1_CH5 | LP_GPIO5 | LP_UART_TXD | MTDI | I1 | GPIO5 | I/O/T | FSPIWP | I1/O/T |  | MTDI | A5 | GPIO5 | LP_GPIO5 | LP_UART_TXD
12 | MTCK | IO | VDDPST1 |  | IE, WPU |  | ADC1_CH6 | LP_GPIO6 | LP_I2C_SDA | MTCK | I1 | GPIO6 | I/O/T | FSPICLK | I1/O/T |  | MTCK | A6 | GPIO6 | LP_GPIO6 | LP_I2C_SDA
13 | MTDO | IO | VDDPST1 |  | IE |  |  | LP_GPIO7 | LP_I2C_SCL | MTDO | O/T | GPIO7 | I/O/T | FSPID | I1/O/T |  | MTDO |  | GPIO7 | LP_GPIO7 | LP_I2C_SCL
14 | GPIO8 | IO | VDDPST2 | IE | IE |  |  |  |  | GPIO8 | I/O/T | GPIO8 | I/O/T
15 | GPIO9 | IO | VDDPST2 | IE, WPU | IE, WPU |  |  |  |  | GPIO9 | I/O/T | GPIO9 | I/O/T |  |  |  | BOOT
16 | GPIO12 | IO | VDDPST2 |  | IE | USB_D- |  |  |  | GPIO12 | I/O/T | GPIO12 | I/O/T |  |  |  | USB_D-
17 | GPIO13 | IO | VDDPST2 |  | IE, WPU | USB_D+ |  |  |  | GPIO13 | I/O/T | GPIO13 | I/O/T |  |  |  | USB_D+
18 | GPIO14 | IO | VDDPST2 |  | IE |  |  |  |  | GPIO14 | I/O/T | GPIO14 | I/O/T |  |  |  | RF Switch
19 | GPIO15 | IO | VDDPST2 | IE | IE |  |  |  |  | GPIO15 | I/O/T | GPIO15 | I/O/T |  |  |  | USER LED
20 | VDDPST2 | Power
21 | U0TXD | IO | VDDPST2 |  | WPU |  |  |  |  | U0TXD | O | GPIO16 | I/O/T | FSPICS0 | I1/O/T |  | D6 | TX | GPIO16
22 | U0RXD | IO | VDDPST2 |  | IE, WPU |  |  |  |  | U0RXD | I1 | GPIO17 | I/O/T | FSPICS1 | O/T |  | D7 | RX | GPIO17
23 | SDIO_CMD | IO | VDDPST2 | WPU | IE |  |  |  |  | SDIO_CMD | I1/O/T | GPIO18 | I/O/T | FSPICS2 | O/T |  | D10 | MOSI | GPIO18 | SDIO_CMD
24 | SDIO_CLK | IO | VDDPST2 | WPU | IE |  |  |  |  | SDIO_CLK | I1 | GPIO19 | I/O/T | FSPICS3 | O/T |  | D8 | SCK | GPIO19 | SDIO_CLK
25 | SDIO_DATA0 | IO | VDDPST2 | WPU | IE |  |  |  |  | SDIO_DATA0 | I1/O/T | GPIO20 | I/O/T | FSPICS4 | O/T |  | D9 | MISO | GPIO20 | SDIO_DATA0
26 | SDIO_DATA1 | IO | VDDPST2 | WPU | IE |  |  |  |  | SDIO_DATA1 | I1/O/T | GPIO21 | I/O/T | FSPICS5 | O/T |  | D3 |  | GPIO21 | SDIO_DATA1
27 | SDIO_DATA2 | IO | VDDPST2 | WPU | IE |  |  |  |  | SDIO_DATA2 | I1/O/T | GPIO22 | I/O/T |  |  |  | D4 | SDA | GPIO22 | SDIO_DATA2
28 | SDIO_DATA3 | IO | VDDPST2 | WPU | IE |  |  |  |  | SDIO_DATA3 | I1/O/T | GPIO23 | I/O/T |  |  |  | D5 | SCL | GPIO23 | SDIO_DATA3
29 | VDDA1 | Power
30 | XTAL_N | Analog
31 | XTAL_P | Analog
32 | VDDA2 | Power
33 | GND | Power
ESP32C6FN4-QFN32 Package Pinout Overview
管脚 序号 | 管脚 名称 | 管脚 类型 1 | 供电 管脚 3-5 | 管脚配置 6,7 |  | 管脚功能 1,2
 |  |  |  | 复位时 | 复位后 | IO MUX | LP IO MUX | 模拟
1 | ANT | 模拟
2 | VDDA3P3 | 电源
3 | VDDA3P3 | 电源 |  |  |  |  |  |  | Table 2-4. QFN32 IO MUX Pin Functions
4 | CHIP_PU | 模拟 | VDDPST1 |  |  |  |  |  | 管脚 序号 | IO MUX / GPIO 名称 | IO MUX 功能
5 | VDDPST1 | 电源 |  |  |  |  |  |  |  |  | 0 | 类型 | 1 | 类型 | 2 | 类型
6 | XTAL_32K_P | IO | VDDPST1 |  |  | IO MUX | LP IO MUX | Analog | 6 | GPIO0 | GPIO0 | I/O/T | GPIO0 | I/O/T
7 | XTAL_32K_N | IO | VDDPST1 |  |  | IO MUX | LP IO MUX | Analog | 7 | GPIO1 | GPIO1 | I/O/T | GPIO1 | I/O/T
8 | GPIO2 | IO | VDDPST1 | IE | IE | IO MUX | LP IO MUX | Analog | 8 | GPIO2 | GPIO2 | I/O/T | GPIO2 | I/O/T | FSPIQ | I1/O/T
9 | GPIO3 | IO | VDDPST1 | IE | IE | IO MUX | LP IO MUX | Analog | 9 | GPIO3 | GPIO3 | I/O/T | GPIO3 | I/O/T
10 | MTMS | IO | VDDPST1 | IE | IE | IO MUX | LP IO MUX | Analog | 10 | GPIO4 | MTMS | I1 | GPIO4 | I/O/T | FSPIHD | I1/O/T
11 | MTDI | IO | VDDPST1 | IE | IE | IO MUX | LP IO MUX | Analog | 11 | GPIO5 | MTDI | I1 | GPIO5 | I/O/T | FSPIWP | I1/O/T
12 | MTCK | IO | VDDPST1 |  | IE, WPU 6 | IO MUX | LP IO MUX | Analog | 12 | GPIO6 | MTCK | I1 | GPIO6 | I/O/T | FSPICLK | I1/O/T
13 | MTDO | IO | VDDPST1 |  | IE | IO MUX | LP IO MUX |  | 13 | GPIO7 | MTDO | O/T | GPIO7 | I/O/T | FSPID | I1/O/T
14 | GPIO8 | IO | VDDPST2 | IE | IE | IO MUX |  |  | 14 | GPIO8 | GPIO8 | I/O/T | GPIO8 | I/O/T
15 | GPIO9 | IO | VDDPST2 | IE, WPU | IE, WPU | IO MUX |  |  | 15 | GPIO9 | GPIO9 | I/O/T | GPIO9 | I/O/T
16 | GPIO12 | IO | VDDPST2 |  | IE | IO MUX |  | Analog | 16 | GPIO12 | GPIO12 | I/O/T | GPIO12 | I/O/T
17 | GPIO13 | IO | VDDPST2 | USB_PU | IE, USB_PU | IO MUX |  | Analog | 17 | GPIO13 | GPIO13 | I/O/T | GPIO13 | I/O/T
18 | GPIO14 | IO | VDDPST2 |  | IE | IO MUX |  |  | 18 | GPIO14 | GPIO14 | I/O/T | GPIO14 | I/O/T
19 | GPIO15 | IO | VDDPST2 | IE | IE | IO MUX |  |  | 19 | GPIO15 | GPIO15 5b | I/O/T | GPIO15 | I/O/T
20 | VDDPST2 | 电源
21 | U0TXD | IO | VDDPST2 |  | WPU 7 | IO MUX |  |  | 21 | GPIO16 | U0TXD | O | GPIO16 | I/O/T | FSPICS0 | I1/O/T
22 | U0RXD | IO | VDDPST2 |  | IE, WPU | IO MUX |  |  | 22 | GPIO17 | U0RXD | I1 | GPIO17 | I/O/T | FSPICS1 | O/T
23 | SDIO_CMD | IO | VDDPST2 | WPU | IE | IO MUX |  |  | 23 | GPIO18 | SDIO_CMD | I1/O/T | GPIO18 | I/O/T | FSPICS2 | O/T
24 | SDIO_CLK | IO | VDDPST2 | WPU | IE | IO MUX |  |  | 24 | GPIO19 | SDIO_CLK | I1 | GPIO19 | I/O/T | FSPICS3 | O/T
25 | SDIO_DATA0 | IO | VDDPST2 | WPU | IE | IO MUX |  |  | 25 | GPIO20 | SDIO_DATA0 | I1/O/T | GPIO20 | I/O/T | FSPICS4 | O/T
26 | SDIO_DATA1 | IO | VDDPST2 | WPU | IE | IO MUX |  |  | 26 | GPIO21 | SDIO_DATA1 | I1/O/T | GPIO21 | I/O/T | FSPICS5 | O/T
27 | SDIO_DATA2 | IO | VDDPST2 | WPU | IE | IO MUX |  |  | 27 | GPIO22 | SDIO_DATA2 | I1/O/T | GPIO22 | I/O/T
28 | SDIO_DATA3 | IO | VDDPST2 | WPU | IE | IO MUX |  |  | 28 | GPIO23 | SDIO_DATA3 | I1/O/T | GPIO23 | I/O/T
29 | VDDA1 | 电源
30 | XTAL_N | 模拟
31 | XTAL_P | 模拟
32 | VDDA2 | 电源
33 | GND | 电源

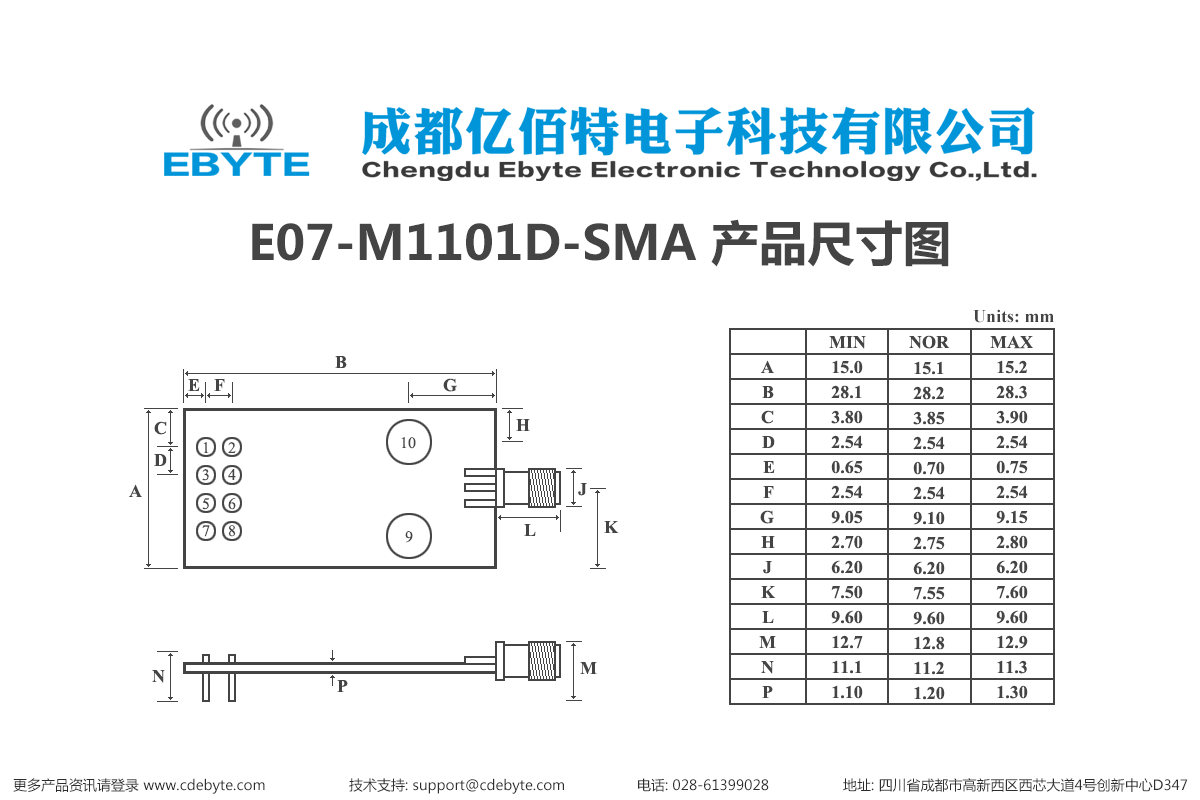
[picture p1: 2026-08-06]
doc/CC1101/E07 (M1101D-SMA)/M07-M1101D_SPEC.png

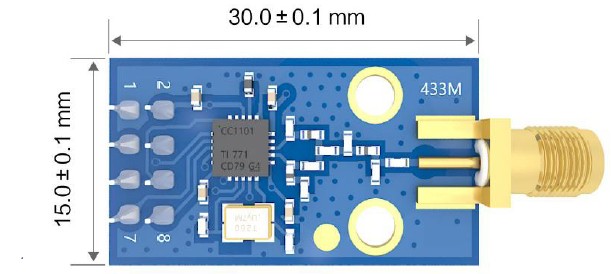
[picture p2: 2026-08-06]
doc/CC1101/E07 (M1101D-SMA)/EBYTE-E07-M1101D-SMA-CC1101-433MHz-DIP-Wireless-Module-fig-1.jpg

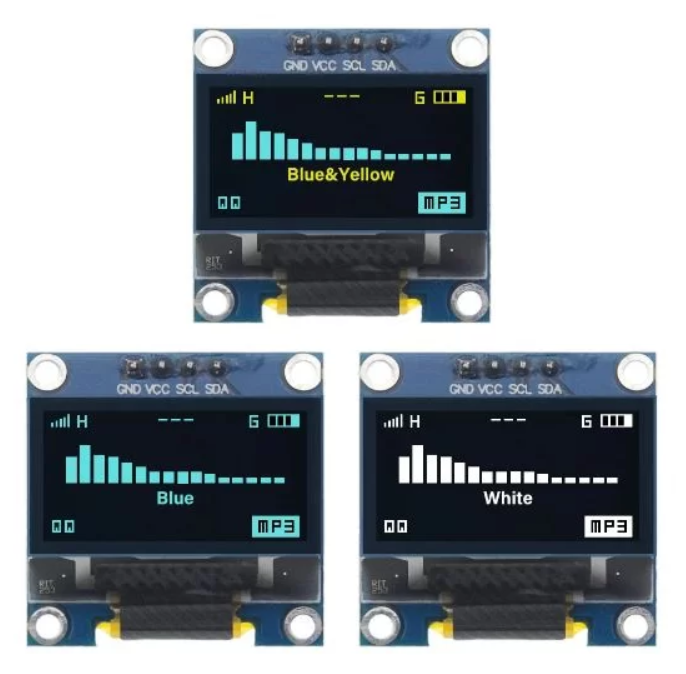
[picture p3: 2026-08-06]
doc/display/i2c-oled-128x64-display-module-1.snapshot.4/Capture.PNG

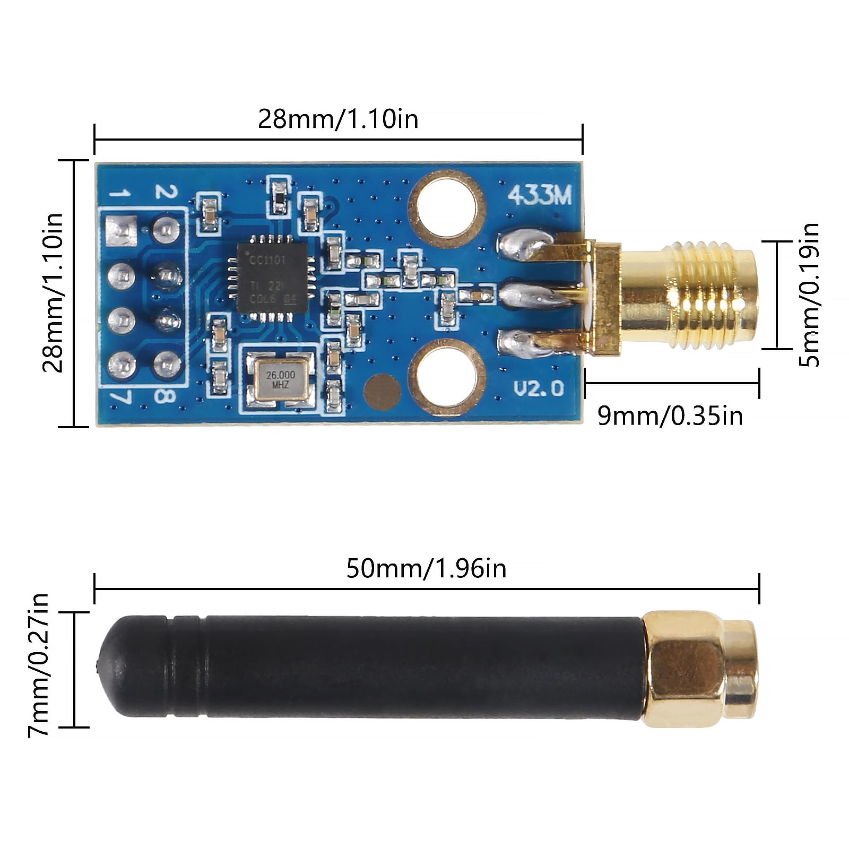
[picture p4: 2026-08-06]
doc/CC1101/E07 (M1101D-SMA)/M07-M1101D_1.jpg

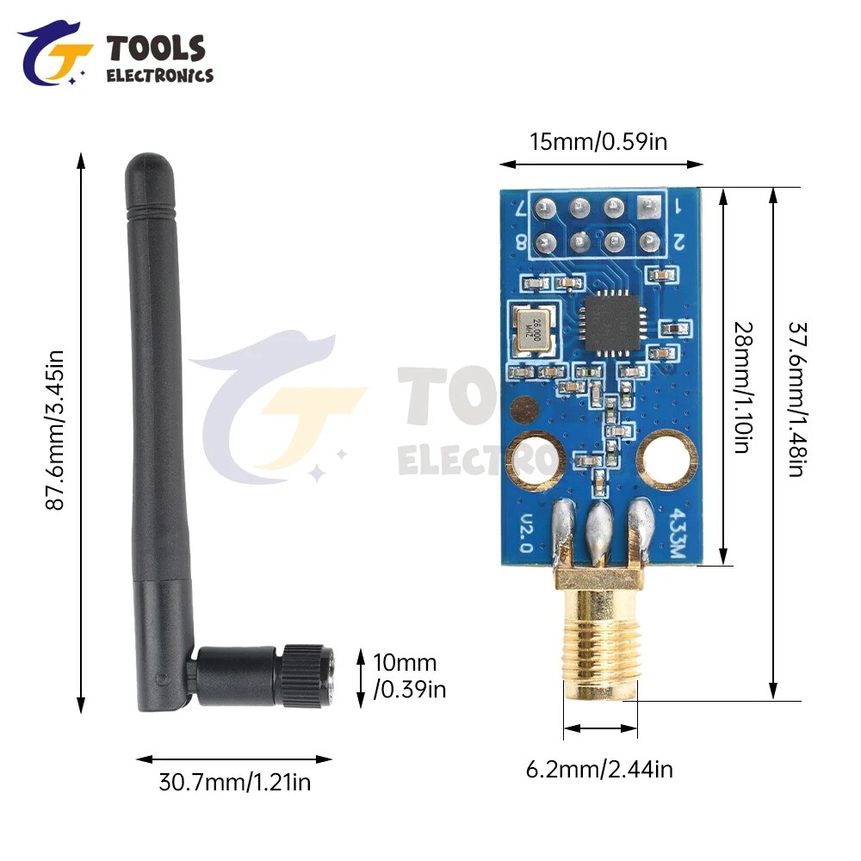
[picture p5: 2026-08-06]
doc/CC1101/E07 (M1101D-SMA)/M07-M1101D_2.jpg

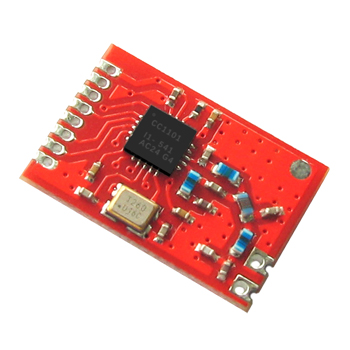
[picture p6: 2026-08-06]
doc/CC1101/E07 (M1101S)/E07-M1101S.jpg

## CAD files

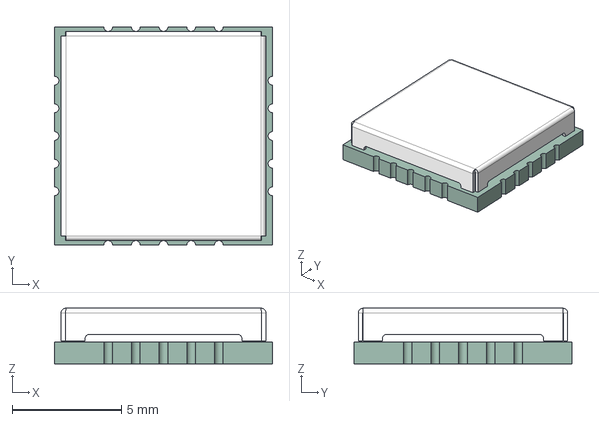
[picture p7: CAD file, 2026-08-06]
doc/CC1101/E07-400MM10S.step
10.0 x 10.0 x 2.55 mm
PBZ-135
10705-V1.1_PCB

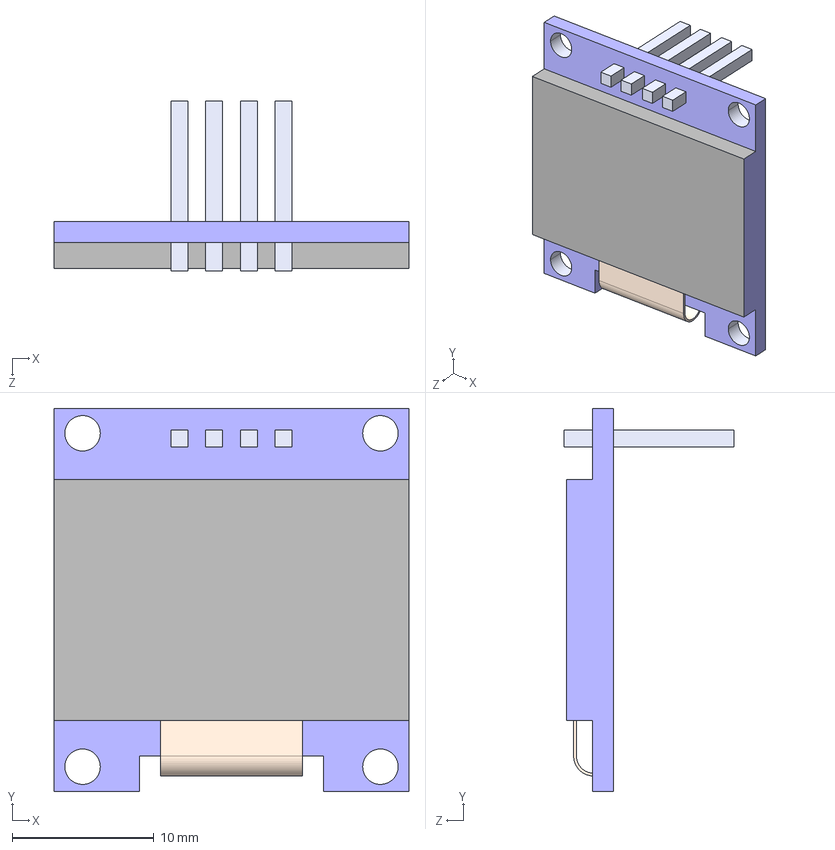
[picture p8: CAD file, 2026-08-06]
doc/display/i2c-oled-128x64-display-module-1.snapshot.4/I2C OLED 128×64 Display Module.STEP
25.0 x 27.0 x 12.0 mm

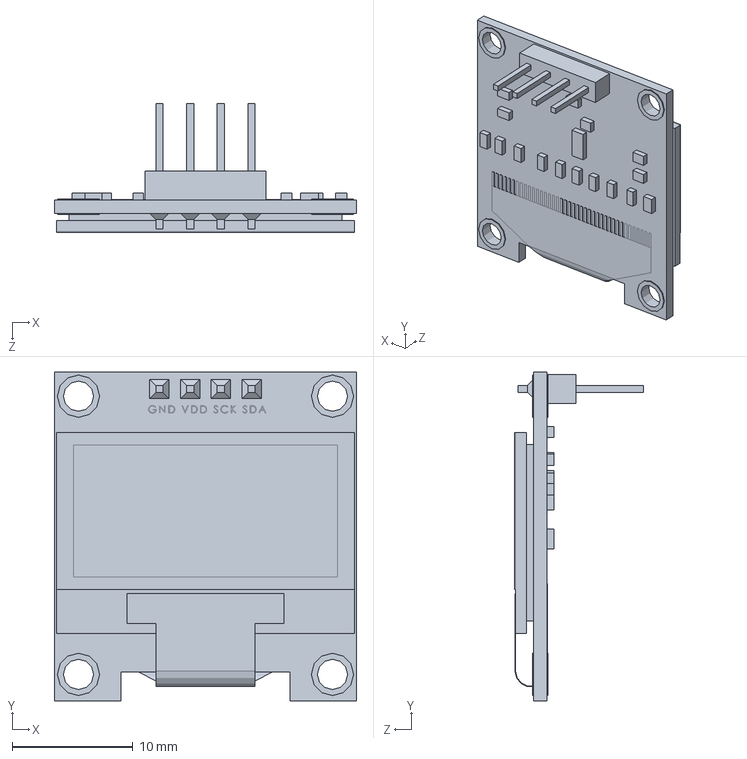
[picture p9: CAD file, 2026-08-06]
doc/display/oled-0-96-inch-128x64px-1.snapshot.2/OLED-128x64-0.96 (SMALL SIZE).SLDPRT
25.0 x 27.2 x 10.7 mm

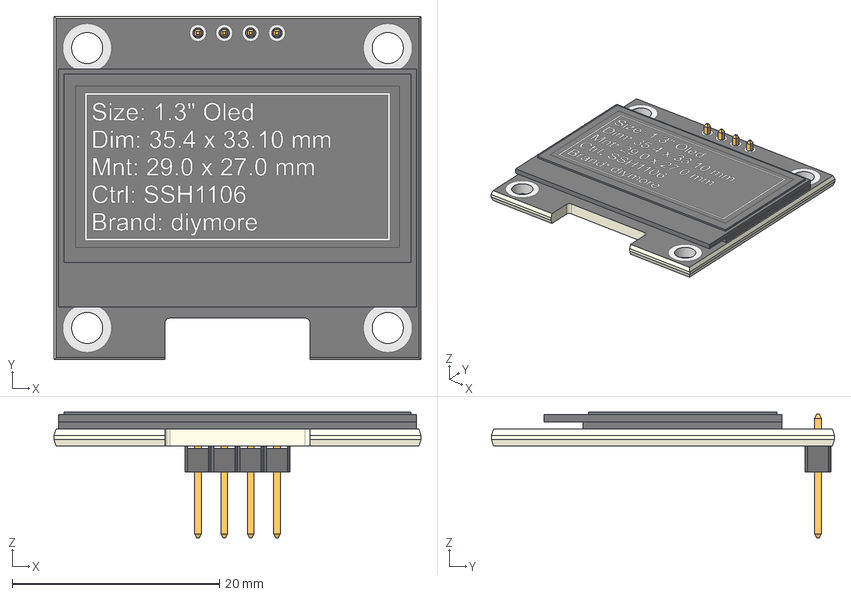
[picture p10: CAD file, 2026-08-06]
doc/display/oled-1-3-ssd1309-tzt-1.snapshot.2/Oled 1.3 Inch SSH1106 diymore.step
35.4 x 33.1 x 12.1 mm
PCB
Display
4-Pin Header - Male - 2.54mm

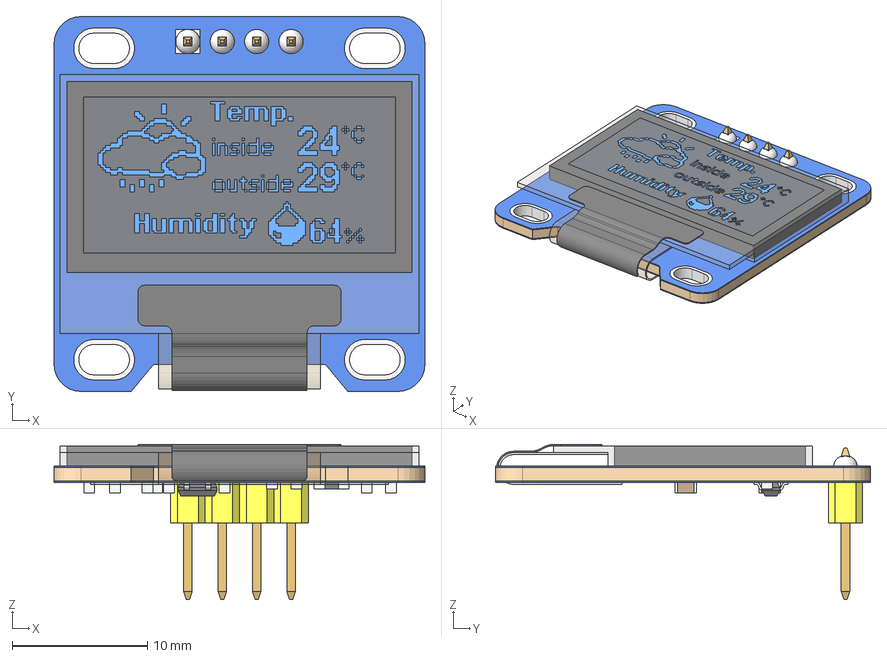
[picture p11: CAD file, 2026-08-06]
doc/display/oled-display-128-x-64-i2c-0-96-1.snapshot.7/OLED 128 x 64 Display 0.96 Inch.step
27.4 x 27.7 x 11.5 mm

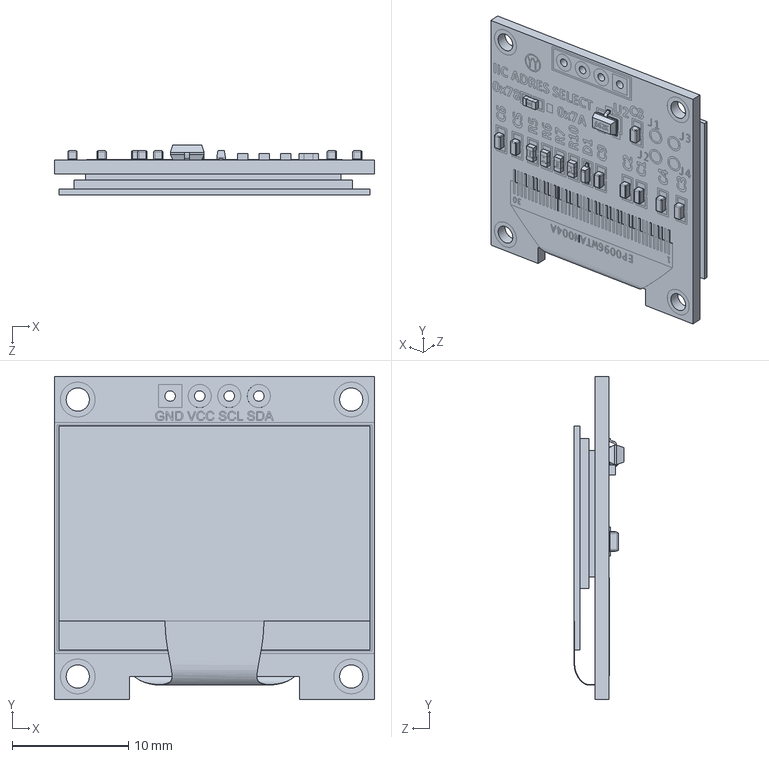
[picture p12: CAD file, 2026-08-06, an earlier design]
doc/display/oled-0-96-inch-128x64px-old-pcb-1.snapshot.3/OLED-128x64-0.96 (BIG SIZE).SLDPRT
27.5 x 27.8 x 4.31 mm

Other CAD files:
doc/display/oled-display-128-x-64-i2c-0-96-1.snapshot.7/OLED 128 x 64 Display 0.96 Inch.FCStd

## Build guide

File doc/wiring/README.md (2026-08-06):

# 배선도 (보드별)

보드마다 핀 배열이 다르므로 배선 문서를 **보드별로 분리**한다. 각 문서의 핀맵은
대응하는 `main/boards/<board>.h` 헤더(= 단일 진실원천)에서 파생한다.

| 보드 | 문서 | SoC | OLED | Matter PID | 상태 |
|---|---|---|---|---|---|
| **GNPE ESP32-C6-0.42** | [`wiring_gnpe-c6.md`](wiring_gnpe-c6.md) · [상세 HTML](wiring_gnpe-c6.html) | ESP32-C6 | 내장 0.42" 72×40, **180° 회전** | `0x8000` | ✅ 검증 |
| **Seeed XIAO ESP32-C6** | [`wiring_xiao-c6.md`](wiring_xiao-c6.md) | ESP32-C6 | 외부 0.96" 128×64, **정방향** | `0x8003` | ✅ 검증 (**I2C 공유**) |
| **ESP32-H2 SuperMini** | [`wiring_esp32-h2.md`](wiring_esp32-h2.md) | ESP32-H2 | 외부 모듈 | `0x8001` | ✅ 검증 (SuperMini 핀 반영, **I2C 공유**) |

> 📺 **디스플레이 규격은 보드별로 다르다** — `boards/<board>.h` 의 `BOARD_OLED_*`
> (해상도/오프셋/회전/72×40 보정/주소)가 단일 진실원천. 컬럼 오프셋만 라이브러리
> 제약상 `sdkconfig` 의 `CONFIG_OFFSETX` 와 짝을 맞춘다(GNPE 28 / XIAO 0).
>
> 🔀 **렌더러는 "해상도"로 자동 선택**(보드 무관) — 펌웨어(`oled_ui.c`)는
> `BOARD_OLED_WIDTH×HEIGHT` 만 보고 렌더러를 고른다(`oled_ui.h` 의 `OLED_RENDER_*`).
>
> | 해상도 | 렌더러 |
> |---|---|
> | **128×64 (가로)** | 풀스크린 네이티브 — 고딕 폰트 + 7세그 시계 (가로 배치) |
> | **64×128 (세로)** | 풀스크린 네이티브 — 고딕 폰트 + 7세그 시계 (세로 적층) |
> | **그 외** | 72×40 논리 캔버스 (어떤 패널에도 중앙 배치) |
>
> 따라서 **어느 보드든 OLED 를 다른 규격으로 교체 가능** — 보드 헤더의 `BOARD_OLED_*`
> 만 바꾸면 맞는 렌더러가 자동 적용된다(코드 수정 불필요). 예: 128×64 → `BOARD_OLED_*`
> 를 128×64/OFFSET 0/FIXUP 0, 세로 64×128(SH1107 등) → 64×128 으로 선언.

> ⚠️ **핀맵의 단일 진실원천은 `main/boards/<board>.h`** 다. 문서가 헤더와 상충하면
> 헤더(+ 루트 `README.md`)가 우선이다. `wiring_gnpe-c6.html` 의 일부 버전 이력
> 섹션은 과거 표기를 보존하므로 현행과 다를 수 있다.

## 공통 사항 (모든 보드)

- **CC1101 은 3.3V 전용** — 5V 연결 시 즉시 파손.
- **PCF8574 / PCF8575** I2C 확장칩(주소 `0x20`, A0/A1/A2 → GND) — 버튼·로터리를 한 칩에
  모아 읽는다. 외부 풀업 SDA/SCL **4.7 kΩ** · ~INT **10 kΩ** → +3V3. 좌/우 버튼 유무로
  칩 분기(`BOARD_HAS_LR_BUTTONS`). **상세 핀맵·배선표 ↓ [§PCF8574 / PCF8575 핀맵·배선](#pcf8574--pcf8575-핀맵배선).**
- **I2C 버스 구성 (`BOARD_I2C_SHARED`)**:
  - **분리(GNPE)**: OLED=하드웨어 I2C, PCF8574=소프트웨어 비트뱅 — 서로 다른 핀.
  - **공유(XIAO·H2)**: OLED 와 PCF8574 가 **하드웨어 I2C 한 버스** (SDA/SCL 동일 핀,
    주소만 0x3C/0x20). 펌웨어가 PCF8574 를 OLED 버스의 device 로 폴링.
  - **XIAO 는 런타임 자동 폴백**(`BOARD_I2C_LP_FALLBACK=1`): 부팅 시 **LP_I2C(뒷면 MTCK=6/
    MTDO=7) 비트뱅**으로 PCF8574 를 먼저 프로브 → 무응답이면 **공유 HW I2C(D4/D5=GPIO22/23)**
    로 자동 전환. 한 펌웨어가 두 배선(뒷면 LP / 앞면 공유)을 모두 지원(택1 불필요).
- Light-sleep wake 소스: PCF8574 ~INT(버튼/로터리) · VIBE(진동) · CHG_STAT(충전).
- 보드 추가/교체 방법: `main/boards/` 에 `<brand>-<soc>.h` 추가 → `board_select.h`
  분기 → `build.ps1` `$BoardMap` 등록. (자세히는 루트 `README.md`)

---

### PCF8574 / PCF8575 핀맵·배선

버튼·로터리 입력을 한 I2C 칩으로 모은다. 좌/우 버튼이 없으면 **PCF8574**(8비트),
있으면 **PCF8575**(16비트)를 `BOARD_HAS_LR_BUTTONS` 로 분기한다. 핀↔신호 매핑의
단일 진실원천은 `main/button_handler.h`, 보드별 SDA/SCL/INT 핀은 `main/boards/<board>.h`.

**① 핀 ↔ 신호 매핑**

| 핀 | 비트 | 신호 | 펌웨어 매크로 | 칩 | 스위치 |
|---|---|---|---|---|---|
| P0 | 0 | ROT_A | `PCF8574_BIT_ROT_A` | 공통 | 로터리 A상 |
| P1 | 1 | ROT_B | `PCF8574_BIT_ROT_B` | 공통 | 로터리 B상 |
| P2 | 2 | ROT_BTN | `PCF8574_BIT_ROT_BTN` | 공통 | 로터리 푸시 |
| P3 | 3 | SETUP | `PCF8574_BIT_SETUP_BTN` | 공통 | SW6 |
| P4 | 4 | UP | `PCF8574_BIT_BTN_UP` | 공통 | SW1 |
| P5 | 5 | DOWN | `PCF8574_BIT_BTN_DOWN` | 공통 | SW2 |
| P6 | 6 | SELECT | `PCF8574_BIT_BTN_SEL` | 공통 | SW3 |
| P7 | 7 | PROG | `PCF8574_BIT_BTN_PROG` | 공통 | SW4 |
| P10 | 8 | LEFT | `PCF8574_BIT_BTN_LEFT` | **8575 전용** | 좌 버튼 |
| P11 | 9 | RIGHT | `PCF8574_BIT_BTN_RIGHT` | **8575 전용** | 우 버튼 |
| P12~P17 | 10~15 | — | (미사용) | 8575 여유 | — |

> 모든 입력 **active-LOW**(눌림=0). 펌웨어가 `0xFF` 를 써 입력으로 두고 칩 내부 약풀업
> 으로 평상시 HIGH. 좌/우(P10·P11)는 `BOARD_HAS_LR_BUTTONS=1` 일 때만 유효.

**② 버스측 배선 (PCF8574·PCF8575 동일)**

| 칩 핀 | 연결 | 풀업 |
|---|---|---|
| VCC | +3V3 (CC1101 과 동일 3.3V) | — |
| GND | GND | — |
| SDA | MCU SDA (보드별 ③) | 4.7 kΩ → +3V3 |
| SCL | MCU SCL (보드별 ③) | 4.7 kΩ → +3V3 |
| ~INT | MCU wake 핀 (보드별 ③) | 10 kΩ → +3V3 |
| A0·A1·A2 | GND | — (→ 주소 `0x20`) |

**③ 보드별 SDA / SCL / ~INT** (출처: `boards/<board>.h`)

| 보드 | SDA | SCL | ~INT | I2C 버스 |
|---|---|---|---|---|
| GNPE C6 | `19` | `18` | `17` | 분리 (OLED=HW · PCF=SW 비트뱅) |
| XIAO C6 — LP_I2C(우선) | `6` (MTCK) | `7` (MTDO) | `2` (D2) | 비트뱅 — 부팅 프로브 시 응답하면 사용 |
| XIAO C6 — 공유(폴백) | `22` (D4) | `23` (D5) | `2` (D2) | OLED HW I2C — LP 무응답 시 자동 전환 |
| H2 SuperMini | `13` (GP13) | `14` (GP14) | `11` (GP11) | OLED 와 HW I2C 공유 |

> 현재 세 보드 모두 **PCF8574** 사용(좌/우 버튼 미장착). 좌/우 버튼을 달면 같은
> 배선·주소 그대로 **PCF8575** 로 교체하고 `BOARD_HAS_LR_BUTTONS=1` 만 켠다.

**④ PCF8574 vs PCF8575**

| 항목 | PCF8574 | PCF8575 |
|---|---|---|
| I/O | 8 (P0~P7) | 16 (P00~P07 · P10~P17) |
| 주소 | `0x20` | `0x20` (동일) |
| read | 1 byte | 2 byte (`PCF_NBYTES`) |
| 좌/우 버튼 | ✗ | ✓ P10·P11 |
| 펌웨어 플래그 | `BOARD_HAS_LR_BUTTONS=0` | `=1` |
| 패키지 | 16핀 (DIP/SO/TSSOP) | 24핀 (SSOP/TSSOP) |

> 두 칩은 P0~P7 핀배치·주소·~INT 동작이 같은 **16비트 형제**. 보드 배선·풀업은
> 그대로 두고 칩만 교체하면 되며, 펌웨어는 플래그로 read 바이트 수를 1↔2 로 바꾼다.

**⑤ 로터리 디텐트 타입 (`BOARD_ROT_HALF_STEP`)**

| 값 | 인코더 | rest 위치 | 디텐트/사이클 | 디코더 (보드) |
|---|---|---|---|---|
| `0` | EC11 (full-step) | `11` | 1 | 단순 상태천이 (GNPE·H2) |
| `1` | EC05 (half-step) | `11`·`00` | 2 | 그레이코드 LUT 누산·바운스 상쇄 (XIAO) |

> 방향이 반대로 느껴지면 `button_handler.c` 의 `_ROT_CW_ON_AB1` 를 뒤집는다.
> 좌/우 버튼 동작 정의는 루트 `README.md` §좌/우 버튼.

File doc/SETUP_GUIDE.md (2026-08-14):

# 조립 및 설치 가이드 (v3.9 / Matter over Thread)

> 📋 PCB 변형의 자세한 비교 + 발주 옵션은 [`kicad/FINAL_REPORT.md`](../kicad/FINAL_REPORT.md) 참조.
>
> **v3.0 (2026-05-13) 부터** SmartThings 연동이 WiFi → **Matter over Thread (802.15.4)** 로 변경되었습니다.
> WiFi SoftAP 프로비저닝은 더 이상 사용되지 않으며, **Thread Border Router** 가 필요합니다 (SmartThings Hub v3+, Apple TV 4K, Google Nest Hub 2nd gen 등).

## 1단계: PCB 변형 선택

현재 4종: **base / _y / _v2 / _h2** (구 `_v`, `_h` 는 삭제됨).

| 변형 | 형태 | 특징 | 추천 사용처 |
|---|---|---|-----|
| **base** | USB-C 직결 | 배터리 없음, 가장 단순 | 개발/데모, 책상용 |
| **_y** | **Jung(융) 스위치 스타일** | 벽 매입 스위치 폼팩터 | 벽 고정형 리모컨 |
| **_v2** | sandwich 분리형 | 배터리, EC05 + STOP, **진동 wake** | 양산형 (추천) |
| **_h2** | sandwich 통합형 | 배터리, EC11 SMD, **진동 wake** | 양산형 컴팩트 (추천) |

> ℹ️ `_y`(Jung 스위치 스타일)의 상세 BOM·배터리/로터리 구성은 `kicad/` 의
> 해당 변형 파일 기준 — 본 표는 폼팩터만 표기.

발주 시: `kicad/gerber/<variant>.zip` 파일을 PCB 제조사에 업로드.

---

## 2단계: 준비물

| 부품 | y | y2 | v2 | v3 | v4 | h2 | h3 | h4 | 규격 / 비고 |
|---|---|---|---|---|---|---|---|---|---|
| ESP32-C6 or ESP32-H2 | GNPE-C6 | XIAO-C6 | GNPE-C6 | H2 | XIAO-C6 | GNPE-C6 | H2 | XIAO-C6 | GNPE ESP32-C6-0.42, XIAO ESP32-C6, ESP32-H2 SuperMini |
| CC1101 모듈 | 1 | 1 | 1 | 1 | 1 | 1 | 1 | 1 | 433/447 MHz, 안테나 분리형 추천 |
| PCF8574 or PCF8575 IC | 8574 | 8574 | 8574 | 8574 | 8574 | 8574 | **8575** | **8575** | SOIC-16W, I2C GPIO 확장. **좌/우 버튼 추가 시 → PCF8575**(SSOP-24, 핀호환)로 교체 |
| EC11 or EC05 로터리 엔코더 | EC11 | EC11 | EC05 | EC05 | EC05 | EC11 | **ANO** | **ANO** | 클릭 버튼 포함, 스위치 대체 가능 |
| 택트 스위치 | 5 | 5 | 5 | 5 | 5 | 5 | 3 | 3 | UP / DOWN / SELECT / PROG / SETUP (+ **LEFT / RIGHT** — PCF8575 시) |
| 3.5mm 스위치 |  |  | 1 | 1 | 1 |  |  |  | STOP(MY) |
| 디커플링 캐패시터 100 nF | 3 | 4 | 3 | 3 | 4 | 3 | 3 | 4 | 1206 SMD, U1/U2/U3 VCC 근처 |
| 전해 캐패시터 10 µF | 1 | 1 | 1 | 1 | 1 | 1 | 1 | 1 | 0805 SMD, +3V3 rail 벌크 |
| I2C 풀업 저항 4.7kΩ | 2 | 4 | 2 | 2 | 4 | 2 | 2 | 4 | 0805 SMD, I2C 근처 SDA/SCL 각각. ⚠️**수량은 "버스 1개" 기준** — **I2C 버스가 2개면 2쌍(4개)**. 예: xiao-c6 에서 PCF8574 를 **LP_I2C(GP6/7)** 로 빼면 OLED(GP22/23)와 버스가 분리되므로 **각 버스에 1쌍씩 필수**(OLED 쪽 누락 시 내부 풀업 45kΩ만 남아 400k·100k 모두 동작 불가 → 화면 안 켜짐). [wiring_xiao-c6.md](wiring/wiring_xiao-c6.md) 참조 |
| INT 풀업 저항 10kΩ | 1 | 1 | 1 | 1 | 1 | 1 | 1 | 1 | 0805 SMD, INT 근처 |
| 402560 LiPo 700 mAh |  |  | 1 | 1 | 1 | 1 | 1 | 1 | PCM 내장 셀, JST PH 2-pin 커넥터 |
| **[충전]** MCP73831T-2ACI/OT |  |  | 1 |  |  | 1 |  |  | SOT-23-5 충전 IC |
| **[충전]** SS14 |  |  | 1 |  |  | 1 |  |  | SMA 패키지, 1A 40V Schottky 전원경로 |
| **[충전]** 저항 3.3kΩ, 1kΩ |  |  | 각 1 |  |  | 각 1 |  |  | 0805 SMD (PROG / LED 제한) |
| **[충전]** 캐패시터 4.7µF |  |  | 2 |  |  | 2 |  |  | 0805 SMD (입력/출력 디커플링) |
| **[충전]** Red LED |  |  | 1 |  |  | 1 |  |  | 0805 SMD 충전 인디케이터 |
| **[충전확인]** 저항 100kΩ |  |  |  | 4 | 4 |  | 4 | 4 | 0805 SMD, CHG_STAT, BAT_ADC |
| SGDBM + SGDBF BTB 터미널 |  |  | 각 2 |  |  | 각 2 |  |  | 2×5 0.8mm pitch |
| 5핀,6핀 커낵터 |  |  |  | 각 1 | 각 1 |  |  |  | 1.24mm pitch, H : 4mm (HEADER 포함) |
| C08 or C02 진동 센서 |  |  | C02 | C02 | C02 | C02 | C02 | C02 | 1210 or 0805 SMD ball type |

---

## 2단계: CC1101 배선

> ⚠️ **핀맵 단일 진실원천은 `main/boards/<board>.h` + `README.md` 다.**
> 아래는 **기본 보드 GNPE ESP32-C6-0.42**(`boards/gnpe-c6.h`) 기준이며, 검증 핀은
> **SCK=IO6, MOSI=IO7, MISO=IO2, CSN=IO4, GDO0=IO8** 이다(FSPI IO-MUX 네이티브).
> 다른 보드(XIAO ESP32-C6 / ESP32-H2 SuperMini 등)는 핀·디스플레이·I2C 구성이
> 다르므로 [`doc/wiring/`](wiring/) 의 보드별 배선도를 따를 것. 상충 시 보드 헤더/README 우선.

### 보드별 핀 맵핑 (요약)

세 보드는 같은 SoC(C6) 라도 핀이 모두 다르다. 단일 진실원천은 각 `boards/<board>.h`.
(`‡` = OLED·PCF8574 가 **같은 I2C 핀 공유**.)

| 신호 | **GNPE C6-0.42** | **XIAO ESP32-C6** | **ESP32-H2 SuperMini** |
|---|---|---|---|
| CC1101 SCK  | IO6 | D8 (GPIO19) | GP4 |
| CC1101 MISO | IO2 | D9 (GPIO20) | GP0 |
| CC1101 MOSI | IO7 | D10 (GPIO18) | GP5 |
| CC1101 CSN  | IO4 | D3 (GPIO21) | GP1 |
| CC1101 GDO0 | IO8 | D6 (GPIO16) | GP10 |
| OLED SDA | IO1 | D4 (GPIO22) | GP13 ‡ |
| OLED SCL | IO0 | D5 (GPIO23) | GP14 ‡ |
| PCF8574 SDA | IO19 (비트뱅) | LP 6 ↔ 공유 22 (자동폴백) | GP13 ‡ (공유) |
| PCF8574 SCL | IO18 (비트뱅) | LP 7 ↔ 공유 23 (자동폴백) | GP14 ‡ (공유) |
| PCF8574 ~INT | IO17 | D2 (GPIO2) | GP11 |
| CHG_STAT | IO3 (active-LOW) | D7 (GPIO17, active-HIGH) | GP12 (active-HIGH) |
| BAT ADC | — | D1 (GPIO1) | GP3 |
| VIBE | IO16 | D0 (GPIO0) | GP2 |

| 항목 | GNPE C6-0.42 | XIAO ESP32-C6 | ESP32-H2 SuperMini |
|---|---|---|---|
| OLED 규격 | 72×40 (180° 회전) | 128×64 (정방향) | 72×40 (외부 모듈, 교체 가능) |
| I2C 버스 | 분리 (OLED HW + PCF 비트뱅) | LP_I2C(6/7)→공유(22/23) **자동폴백** | 공유 (OLED+PCF 한 HW I2C) |
| 로터리 | EC11 (full-step) | EC05 (half-step) | EC11 (기본) |
| 충전 | MCP73831(외부) 600mAh/300mA | 온보드 SGM40567 500mAh/120mA | 온보드 TP4054 400mAh/100mA |
| Matter PID | `0x8000` | `0x8003` | `0x8001` |
| 상태 | ✅ 검증 | ✅ 검증 | ✅ 검증 |

> 핀은 `boards/<board>.h` 의 `BOARD_PIN_*`/`BOARD_OLED_*` 가 기준. 보드별 상세 배선도는
> [`doc/wiring/`](wiring/) 참고. **아래 3~5단계의 상세 배선/이미지는 GNPE 기준**이다.

### 보드 GPIO 핀맵 — GNPE ESP32-C6-0.42

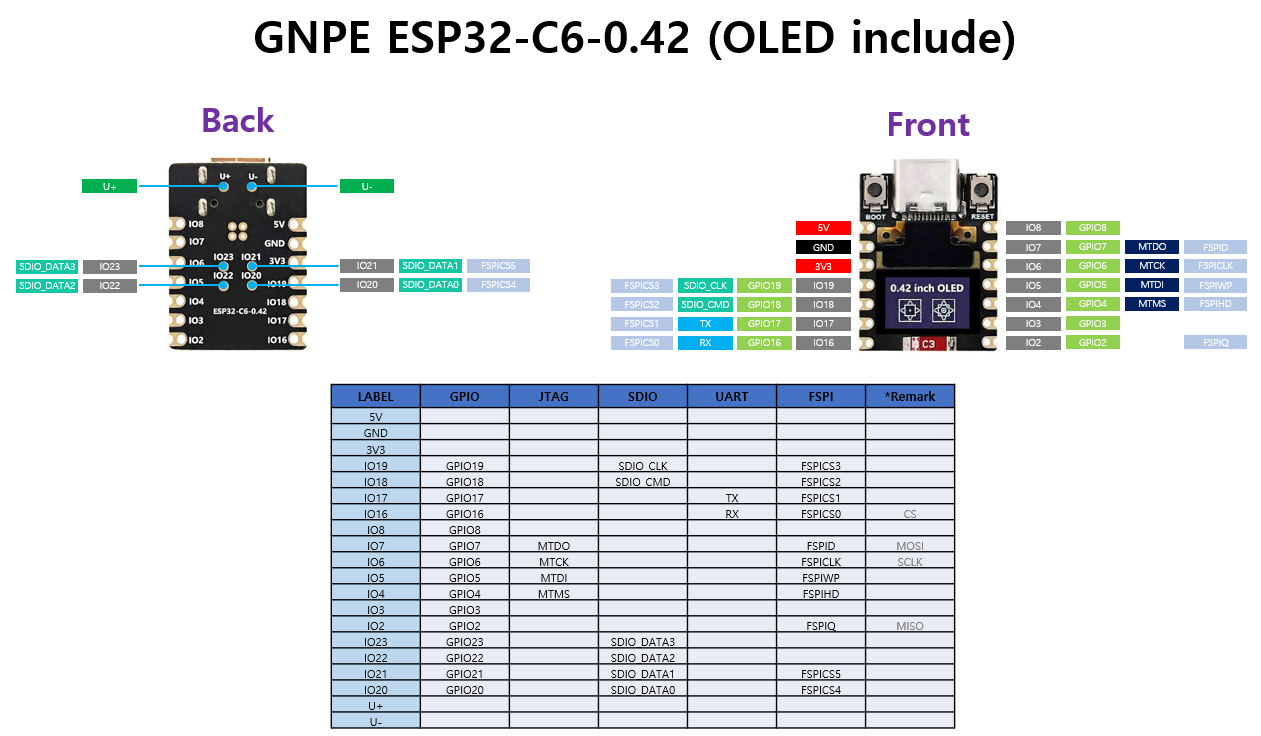
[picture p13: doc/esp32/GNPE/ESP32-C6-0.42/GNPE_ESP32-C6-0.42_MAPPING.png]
GNPE ESP32-C6-0.42 핀맵


### CC1101 모듈 핀맵 — E07-M1101D-SMA

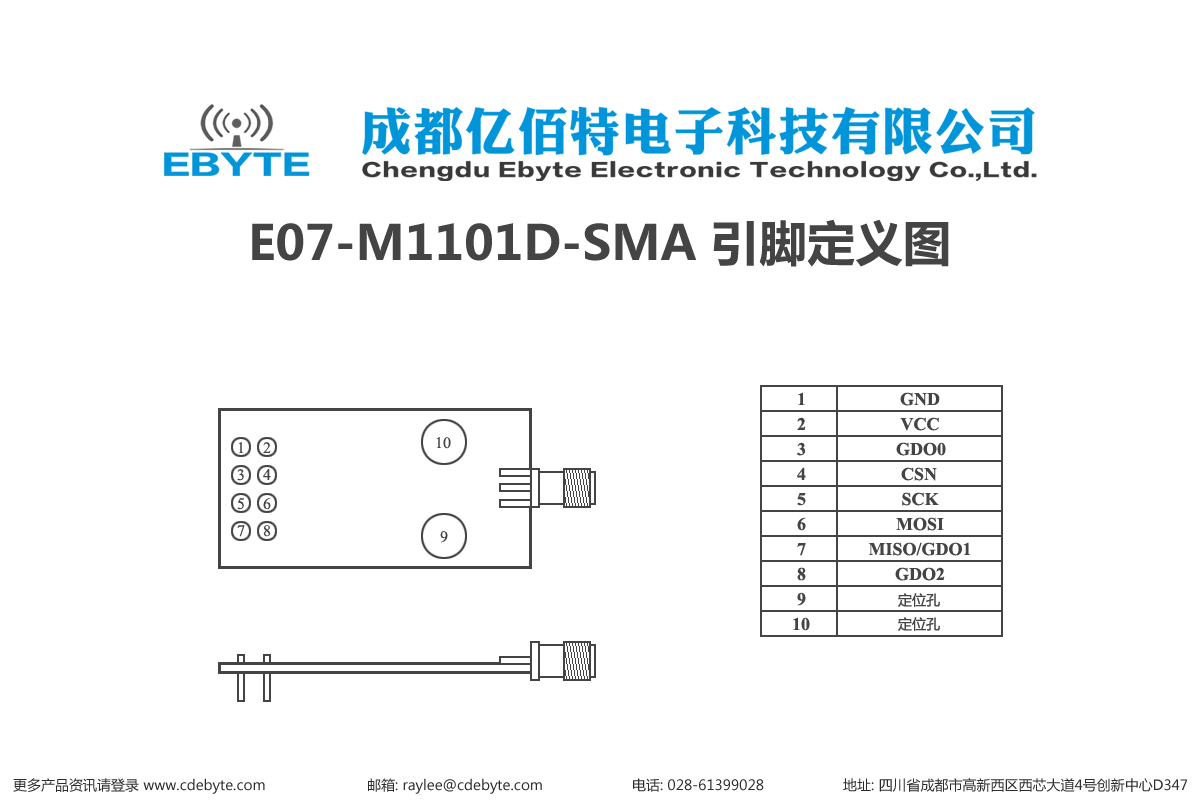
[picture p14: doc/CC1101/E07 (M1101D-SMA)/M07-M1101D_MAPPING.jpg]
E07-M1101D-SMA 핀맵


| CC1101 핀 | 신호명 | ESP32-C6 GPIO | 비고 |
|---|---|---|---|
| Pin 1 GND  | GND | GND  | |
| Pin 2 VCC  | +3.3V | 3V3  | ⚠ 반드시 3.3V! |
| Pin 3 GDO0 | TX Data  | IO8  | RMT 비동기 TX 출력 |
| Pin 4 CSN  | SPI CS | IO4  | |
| Pin 5 SCK  | SPI CLK  | **IO6** | FSPICLK (IO-MUX) |
| Pin 6 MOSI | SPI MOSI | **IO7** | FSPID (IO-MUX) |
| Pin 7 MISO | SPI MISO | **IO2** | FSPIQ (IO-MUX) |
| Pin 8 GDO2 | NC | — | 연결 불필요 |

⚠ **CC1101은 3.3V 전용입니다. 5V 연결 시 즉시 파손됩니다.**

> 📄 CC1101 모듈 상세: [`E07-M1101D-SMA Usermanual EN v1.30`](<./CC1101/E07 (M1101D-SMA)/E07-M1101D-SMA_Usermanual_EN_v1.30.pdf>)
> 보드 상세: [`0.42-ESP32C6`](<./esp32/GNPE/ESP32-C6-0.42/0.42-ESP32C6.pdf>)

---

## 3단계: 버튼/센서 배선 (v2.0 — 모두 PCF8574 이관)

```
컴포넌트         연결                                     비고
──────────────  ──────────────────────────────────────  ───────────
SW1 UP        → PCF8574 P4 (Pin 9)                      ★ v2.0 이관
SW2 DOWN      → PCF8574 P5 (Pin 10)                     ★ v2.0 이관
SW3 SELECT    → PCF8574 P6 (Pin 11)                     ★ v2.0 이관
SW4 PROG      → PCF8574 P7 (Pin 12)                     ★ v2.0 이관 (Somfy PROG)
SW6 SETUP     → PCF8574 P3 (Pin 7)                      ★ v2.0 이관 (짧게 = 설정 메뉴, v3.9)
EC11 ROT_CLICK→ PCF8574 P2                               STOP/MY 커맨드
EC11 ROT_LONG → PCF8574 P2 (2초)                          주파수 편집 모드
VS1 VIBRATION → ESP32 IO16 직결                          wake source
MCP73831 STAT → ESP32 IO3 직결                           wake source
PCF8574 ~INT  → ESP32 IO17 직결 (10kΩ pull-up)           모든 P 변화 wake
```

---

## 4단계: PCF8574 배선 (v2.0 — bit-bang I2C, IO18/IO19)

```
PCF8574 핀    연결 대상             비고
──────────    ──────────────────    ─────────────────────────────────
Pin 1  A0   → GND                  I2C 주소 bit0 = 0
Pin 2  A1   → GND                  I2C 주소 bit1 = 0
Pin 3  A2   → GND                  addr 0x20
Pin 4  P0   → EC11 A상 (ROT_A)
Pin 5  P1   → EC11 B상 (ROT_B)
Pin 6  P2   → EC11 BTN (ROT_BTN)
Pin 7  P3   → SW6 SETUP 버튼       ★ v2.0 변경 (구: CHG_STAT)
Pin 8  GND  → GND
Pin 9  P4   → SW1 BTN_UP           ★ v2.0 변경 (구: VIBRATION)
Pin 10 P5   → SW2 BTN_DOWN         ★ v2.0 변경 (구: SETUP)
Pin 11 P6   → SW3 BTN_SELECT       ★ v2.0 신규
Pin 12 P7   → SW4 BTN_PROG         ★ v2.0 신규
Pin 13 ~INT → IO17 (모든 P 변화 wake) ★ v2.0 신규, 10kΩ pull-up 필수
Pin 14 SCL  → IO18 (bit-bang)      ★ v2.0 변경 (구: LP_GPIO7 IO7)
Pin 15 SDA  → IO19 (bit-bang)      ★ v2.0 변경 (구: LP_GPIO6 IO6)
Pin 16 VCC  → +3.3V
```

> **외부 4.7kΩ pull-up 저항 필수** (SDA/SCL 각 1개씩 to +3.3V).
> ESP32-C6 HP_I2C0 는 OLED 전용, LP_I2C0 는 LP_GPIO6/7 고정 — 따라서 IO18/IO19 는
> 소프트웨어 bit-bang I2C 로 구동 (50kHz, ~10ms 폴링).

**EC11 로터리 엔코더 연결:**
```
EC11 핀    연결
────────   ──────────────────────
A상        PCF8574 P0 (Pin4)
COM/GND    GND
B상        PCF8574 P1 (Pin5)
SW (버튼)  PCF8574 P2 (Pin6)
SWC (COM)  GND
```

### (선택) 좌/우 버튼 — PCF8575 (16핀)

기본 5버튼(UP/DOWN/SELECT/PROG/SETUP) + 로터리(A/B/BTN)가 PCF8574 의 **P0~P7 을 모두**
점유한다. **좌/우 버튼을 추가**하려면 여유 핀이 없으므로 **PCF8574 의 16비트 핀호환
형제 PCF8575(16핀)** 로 교체한다 — 주소(`0x20`) · `~INT` · SDA/SCL · 풀업 · **P0~P7 매핑이
전부 동일**하고 칩만 바꾸면 된다. 추가된 상위 비트 중 2개만 쓴다:

```
PCF8575 추가 핀   연결 대상        비고
─────────────    ────────────     ──────────────────
P10 (bit 8)    → 좌(LEFT) 버튼    active-LOW
P11 (bit 9)    → 우(RIGHT) 버튼   active-LOW
P12~P17        → (미사용)         여유
```

**빌드 플래그**: `boards/<board>.h` 에 `#define BOARD_HAS_LR_BUTTONS 1` → 펌웨어가
PCF8575 로 인식해 **2바이트 read**(P0~7 + P10~17). `0`(기본)이면 PCF8574(1바이트 read).

> **좌/우 버튼 동작** (자세히는 10단계 표):
> - **메인 화면**: 블라인드 선택 **이전 / 다음** (SELECT 순환의 좌우 버전).
> - **시간/날짜 편집**: 자리(필드) 이동.
> - **주파수 편집**: 디지트 **커서 좌/우** 이동(0.1↔0.01 자리) — UP/DOWN(또는 로터리)이 그 자리 값 ±.

---

## 5단계: 빌드 환경 설정

### 5-1. 시스템 환경 변수 설정 (최초 1회)

빌드 스크립트(`build.ps1`)·`CMakeLists.txt`·`factory_nvs_gen.py` 는 개인 경로를
**하드코딩하지 않고 시스템 환경 변수에서 읽는다**. 아래 5개를 **시스템(Machine) 범위**
환경 변수로 등록한다(개인 폴더 구조 비노출). 보통 나머지 4개는 `WORKSPACES_PATH` 아래에 둔다.

| 환경 변수 | 가리키는 곳 | 경로 (WORKSPACES_PATH 하위 기준) |
|---|---|---|
| `WORKSPACES_PATH` | 작업공간 루트(아래 항목들의 부모) | (작업공간 루트 — 직접 지정) |
| `RTS_BLINDS_THREAD_PATH` | **이 프로젝트** 루트 | `%WORKSPACES_PATH%\somfy-blinds-things-by-claude` |
| `IDF_PATH` | ESP-IDF v5.4.1 루트 | `%WORKSPACES_PATH%\esp-idf` |
| `ESP_MATTER_PATH` | esp-matter(CHIP SDK 포함) 루트 | `%WORKSPACES_PATH%\esp-matter` |
| `ESP_SSD1306_PATH` | esp-idf-ssd1306(SSD1306 드라이버) 루트 | `%WORKSPACES_PATH%\esp-idf-ssd1306` |

**관리자 PowerShell 에서 1회 등록** (`$ws` 를 실제 작업공간 경로로 바꿀 것):

```powershell
$ws = "C:\path\to\workspaces"   # esp-idf / esp-matter / 이 프로젝트의 공통 부모
[Environment]::SetEnvironmentVariable('WORKSPACES_PATH',        $ws,                                 'Machine')
[Environment]::SetEnvironmentVariable('RTS_BLINDS_THREAD_PATH', "$ws\somfy-blinds-things-by-claude", 'Machine')
[Environment]::SetEnvironmentVariable('IDF_PATH',               "$ws\esp-idf",                       'Machine')
[Environment]::SetEnvironmentVariable('ESP_MATTER_PATH',        "$ws\esp-matter",                    'Machine')
[Environment]::SetEnvironmentVariable('ESP_SSD1306_PATH',       "$ws\esp-idf-ssd1306",               'Machine')
# 등록 후 새 PowerShell 창을 열어야 적용된다. (또는 시스템 속성 → 환경 변수 GUI 로 등록)
```

> ℹ️ 설치 경로가 위 예와 다르면 각 변수를 실제 경로로 지정하면 된다(서로 다른 폴더에
> 흩어져 있어도 무방 — 각자 독립 변수). 값은 백슬래시(`C:\...`)든 forward slash 든 허용
> (`build.ps1`·`CMakeLists.txt` 가 CMake 용으로 자동 정규화).

**등록 확인** (새 셸에서):

```powershell
'WORKSPACES_PATH','RTS_BLINDS_THREAD_PATH','IDF_PATH','ESP_MATTER_PATH','ESP_SSD1306_PATH' |
  ForEach-Object { "{0,-24} = {1}" -f $_, [Environment]::GetEnvironmentVariable($_) }
```

### 5-2. esp-idf-ssd1306 설치

```bash
git clone https://github.com/nopnop2002/esp-idf-ssd1306 ${WORKSPACES_PATH}\esp-idf-ssd1306
```

### 5-3. esp-matter 설치 (최초 1회)

```bash
git clone --recursive https://github.com/espressif/esp-matter ${WORKSPACES_PATH}\esp-matter
cd ${WORKSPACES_PATH}\esp-matter
# Linux/Mac
./install.sh
# Windows: esp-idf 환경에서 bootstrap 수행
```

### 5-4. 빌드 스크립트 동작 (`build.ps1`)

`build.ps1` 은 경로를 **하드코딩하지 않는다** — 위 5-1 의 시스템 환경 변수
(`RTS_BLINDS_THREAD_PATH`/`IDF_PATH`/`ESP_MATTER_PATH`/`ESP_SSD1306_PATH`)에서 읽고,
pigweed·OTA 도구 경로는 `ESP_MATTER_PATH` 에서 파생한다. 추가로:

- **자동 보충**: 시스템 변수 등록 직후의 기존 셸이면 프로세스에 값이 없을 수 있어
  Machine 스코프에서 자동 로드한다(없으면 `[env] 필수 시스템 환경변수 … 미설정` 에러로 중단).
- **forward slash 정규화**: 환경 변수가 `C:\...`(백슬래시)여도 CMake 용으로 자동 변환.

따라서 5-1 만 끝내면 `build.ps1` 내부를 손댈 필요가 없다.

---

## 6단계: 빌드 & 플래시

> ⚠ **반드시 PowerShell 사용** — Git Bash 는 MSYSTEM 환경변수 충돌로 빌드 실패.
> 사전에 **[§5-1 시스템 환경 변수](#5-1-시스템-환경-변수-설정-최초-1회)** 등록 필수.

모든 빌드/플래시/OTA 는 프로젝트 루트의 **`build.ps1`** 한 스크립트로 한다(보드 선택·로그·
OTA 까지 일원화). 산출물·로그는 보드별로 분리된다.

### 6-1. 보드 선택 (`-Board`)

| `-Board` | 보드 | 빌드 디렉토리 / sdkconfig | 상태 |
|---|---|---|---|
| `gnpe-c6` (기본) | GNPE ESP32-C6-0.42 | `build/` · `sdkconfig` | ✅ 검증 |
| `xiao-c6` | Seeed XIAO ESP32-C6 | `build-xiao-c6/` · `sdkconfig.xiao-c6` | ✅ 검증 |
| `esp32-h2` | ESP32-H2 SuperMini | `build-esp32-h2/` · `sdkconfig.esp32-h2` | ✅ 검증 |

보드마다 **별도 빌드 디렉토리·sdkconfig** 라 전환 시 전체 재컴파일이 불필요하다.
`-Board` 생략 시 기본 `gnpe-c6`.

### 6-2. 표준 작업 흐름

```powershell
# (최초 1회·보드별) IDF target 설정 — 검증 sdkconfig 를 .verified.bak 로 자동 백업
.\build.ps1 -Board gnpe-c6 -Action set-target

# 빌드 → 산출물 build/somfy_blinds.bin
.\build.ps1 -Board gnpe-c6 -Action build

# 플래시 (COM 포트는 6-4 로 확인)
.\build.ps1 -Board gnpe-c6 -Action flash -Port COM3

# 시리얼 모니터 (Ctrl+] 로 종료)
.\build.ps1 -Board gnpe-c6 -Action monitor -Port COM3
```

> XIAO/H2 는 `-Board xiao-c6` / `-Board esp32-h2` 로 바꾸기만 하면 된다(나머지 동일).

### 6-3. 전체 액션 (`-Action`)

| `-Action` | 동작 |
|---|---|
| `build` | 빌드 (산출물 `<builddir>/somfy_blinds.bin`) |
| `flash` | 빌드 후 플래시 (`-Port` 필요) |
| `monitor` | 시리얼 모니터 (네이티브 USB 리셋·재열거 처리, **Ctrl+]** 종료) |
| `erase` | **전체 flash 삭제** (⚠ `rollcode` 파티션까지 → 블라인드 **재-PROG** 필요) |
| `clean` | 빌드 클린 (`fullclean`) |
| `menuconfig` | Kconfig 편집기 |
| `set-target` | IDF target 설정 (검증 sdkconfig 를 `.verified.bak` 로 백업) |
| `restore-sdkconfig` | set-target 후 링크 깨지면 검증 sdkconfig 복원 |
| `ota-image` | `.bin` → 보드별 Matter OTA `.ota` 생성 ([§6-7](#6-7-ota-무선-업데이트)) |

> 모든 출력은 **`logs/<board>-<action>.log`** 로 자동 기록(매 실행 덮어쓰기).
> ⚠ `set-target` 은 sdkconfig 를 defaults 에서 재생성 → WindowCovering 클러스터 등 구성
> 누락으로 **링크 실패**할 수 있다. 그럴 땐 `-Action restore-sdkconfig` 로 복원.

### 6-4. COM 포트 찾기

```powershell
# 연결된 시리얼 포트 나열
Get-PnpDevice -Class Ports -Status OK | Select-Object FriendlyName, InstanceId
# 또는 (간단)
[System.IO.Ports.SerialPort]::GetPortNames()
```

USB 연결 전/후로 비교해 새로 뜨는 포트가 대상(예: `COM6`). XIAO/H2 는 네이티브
USB(USB-Serial-JTAG) 라 `flash`/`monitor` 가 리셋·재열거를 자동 처리한다.

### 6-5. VSCode 태스크

`Ctrl+Shift+B` → 태스크 선택: **Build / Flash / Monitor / Clean** (각 idf.py 대응).

### 6-6. esptool 직접 (참고)

> 💡 **`build.ps1 -Action build` 출력 끝에 정확한 esptool 명령이 그대로 찍힌다 — 이걸
> 복사하는 게 가장 안전하다.** 아래는 GNPE 수동 예(보드별 `--chip`=`esp32c6`/`esp32h2`,
> 빌드 디렉토리=`build` 또는 `build-<board>`):

```powershell
python -m esptool --chip esp32c6 -b 460800 `
  --before default_reset --after hard_reset `
  write_flash --flash_mode dio --flash_size 4MB --flash_freq 80m `
  0x0      build\bootloader\bootloader.bin `
  0xc000   build\partition_table\partition-table.bin `
  0x1d000  build\ota_data_initial.bin `
  0x20000  build\somfy_blinds.bin
```

> ⚠ 오프셋은 **이 프로젝트 파티션 기준**(`partitions.csv`): partition-table `0xc000`,
> otadata `0x1d000`, 앱(`ota_0`) `0x20000`. ESP-IDF 기본값(0x8000/0xf000)과 **다르니**
> 반드시 build 출력 명령을 따를 것.

### 6-7. OTA 무선 업데이트

빌드 후 **무선 배포**는 `-Action ota-image` 로 보드별 `.ota` 를 만들어 Provider/허브로 보낸다.
버전 증가·HW 변형 태그(`<pcf>.<enc>.<oled>`)·배포 절차는 **[`doc/OTA.md`](OTA.md)** 참고.

```powershell
.\build.ps1 -Board gnpe-c6 -Action ota-image   # → dist/somfy_blinds_gnpe-c6_..._v0035.ota
```

### 6-8. 변형 선택 빌드 (OTA 처럼 PCF / 로터리 / OLED)

보드 헤더를 **안 고치고도** 한 보드에서 PCF·로터리·OLED 변형을 빌드 시 고를 수 있다
(`board_select.h` 가 빌드타임 `-D` 오버라이드를 적용). 안 주면 보드 기본값(바이너리 동일).

| 옵션 | 값 | 덮는 매크로 / 효과 |
|---|---|---|
| `-Pcf` | `8574` / `8575` | `BOARD_HAS_LR_BUTTONS` — `8575`=좌/우 버튼 추가 |
| `-Rotary` | `ec11` / `ec05` | `BOARD_ROT_HALF_STEP` — `ec05`=half-step 디코더 |
| `-Oled` | `72x40` / `128x64` / `64x128` | `BOARD_OLED_WIDTH/HEIGHT/FIXUP` — 해상도→렌더러 |
| `-Rotate` | `0` / `180` / `m0` / `m180` | `BOARD_OLED_ROTATE_180` + `BOARD_OLED_FLIP_X` — OLED 회전·좌우반전 (`m` 접두=좌우반전, 아래 표) |
| `-Freq` | `447.70` / `447.72` (미지정=**447.70**) | `BOARD_DEFAULT_FREQ_MHZ` — 기본 송신 주파수 register. 제작보드(E07-400MM10S)=447.70 · 테스트보드(E07-M1101D-SMA)=447.72 (모듈 크리스털 오차 차이) |

**`-Rotate` 방향 값** (`m`=mirror 접두 = 좌우(가로)반전 추가; 회전과 독립 조합):

| 값 | 표시 방향 | 변환 |
|---|---|---|
| `0` | 정방향 | 없음 |
| `180` | 180° 회전 | 좌우+상하 |
| `m0` | **좌우(가로) 반전** | 열 역순 |
| `m180` | 상하(세로) 반전 | `m0`+180° |

```powershell
# GNPE 보드에 좌/우 버튼(PCF8575) + EC05 로 빌드
.\build.ps1 -Board gnpe-c6 -Action build -Pcf 8575 -Rotary ec05

# XIAO 를 EC11 로 (기본 EC05 덮어쓰기)
.\build.ps1 -Board xiao-c6 -Action build -Rotary ec11

# OLED 좌우(가로) 반전 — 거울처럼 뒤집혀 장착된 패널 보정
.\build.ps1 -Board xiao-c6 -Action build -Rotate m0

# ESP32-H2 시제품 기판: OLED 가 180° 장착이라 -Rotate 180 필수 (안 주면 화면 상하 뒤집힘)
.\build.ps1 -Board esp32-h2 -Action build -Rotate 180 -Freq 447.72
```

> 🏷️ **같은 변형 옵션을 `ota-image` 에도 동일하게** 줘야 `.ota` 태그가 빌드와 일치한다:
> `.\build.ps1 -Board gnpe-c6 -Action ota-image -Pcf 8575 -Rotary ec05` → `..._8575_ec05_..._v0035.ota`.

> ⚠ **`-Oled` 해상도만 주의**: 렌더러·패널크기(`ssd1306_init`)는 `-D` 로 바뀌지만, 물리
> **컬럼 오프셋**은 SSD1306 라이브러리 Kconfig(`CONFIG_OFFSETX`, sdkconfig)라 따로
> 맞춰야 정상 표시된다(72x40=28 / 128x64·64x128=0 — build 시 경고 출력).
> PCF·로터리·회전(`-Rotate`)은 sdkconfig 무관, 완전 자동.

### 6-9. 시리얼 콘솔 (진단 / 자동 RF 테스트)

USB Serial JTAG 콘솔에 명령을 보내 **버튼 없이** RF 송신·블라인드 선택·주파수 설정·재부팅을
무인 제어한다 — PC 가 COM 포트로 기기를 구동해 RF 를 쏘고 SDR(`somfy_cli`)로 캡처·분석하는
자동 루프에 쓴다(`read_serial.py` 패턴, 하네스는 `sim/tools/`).

| 명령 | 동작 |
|---|---|
| `tx up\|down\|updown\|myup\|mydown\|my\|prog [hold_ms]` | Somfy RF 송신(session-gate 우회 → combo 직접). `tx up`=cmd2 · `tx updown`=cmd6 |
| `sel <0..N \| N=ALL>` | 블라인드 선택 (N=`BLIND_MAX_COUNT`; H2 `3`·C6 `8`=ALL) |
| `cyc <-1 \| 1>` | 블라인드 선택 순환(`_blind_cycle` — PCF8575 LEFT/RIGHT 의 콘솔 버전) |
| `freq [idx mhz]` | 주파수 조회 / 설정(+NVS 저장, 447.20~447.79 클램프) |
| `reboot` | 재부팅(`esp_restart`) |

> ★ **USB Serial JTAG 를 primary 콘솔**로 둬야 명령 입력이 먹는다(UART default 면 COM 에
> stdin 이 없어 write 가 hang). pyserial 로 **포트를 여러 번 여닫으면 DTR 토글로 리셋**되니
> 한 세션(단일 open) 안에서 연속 전송할 것.

---

## 7단계: Thread Border Router 준비 (v3.0+)

Matter over Thread 는 **Thread Border Router** 가 mesh ↔ Internet 게이트웨이 역할을 합니다.
아래 중 **하나 이상의 장비** 가 Wi-Fi 라우터와 같은 네트워크에 있어야 합니다:

| 장비 | 비고 |
|---|---|
| **SmartThings Hub v3 / Aeotec Smart Home Hub** | 가장 추천 — SmartThings 앱 자동 인식 |
| **SmartThings Station** | 신형, USB-C 전원 |
| Apple TV 4K (2021+) / HomePod mini | Apple Home 사용 시 |
| Google Nest Hub 2nd gen / Nest Hub Max | Google Home 사용 시 |
| Amazon Echo 4th gen / Echo Hub | Alexa 사용 시 |
| OpenThread Border Router (RPi + nRF52840 dongle) | DIY |

> ℹ️ "Thread Border Router 필요" 는 **물리 PCB 배선이 아니라 네트워크 게이트웨이 장비** 의미입니다.
> ESP32-C6 자체가 SED (Sleepy End Device) 로 동작하며 border router 의 Thread mesh 에 join 합니다.

---

## 8단계: Matter over Thread 페어링 (SmartThings)

### 최초 페어링 (v3.5+ 설정 메뉴 사용)

1. ESP32 전원 인가 — Thread network credential 이 없으면 **BLE advertising** 시작 (자동)
2. **SETUP 버튼 (SW6) 짧게 클릭** → 설정 메뉴 진입 (`> Cancel / Freq Edit / Time Set / Matter Pair / Thread Rst / FW Update`). **ESP32-H2 는 메모리 절약으로 `Time Set`·`FW Update` 가 없는 4항목**(Cancel / Freq Edit / Matter Pair / Thread Rst).
3. 로터리 CW/CCW 로 커서를 `> Matter Pair` 까지 이동
4. **SETUP 버튼을 짧게 한 번 클릭** → Matter Pair 화면 진입. ⚠ SELECT 는 설정 모드에서 무시됨 — 메뉴 진입·항목 활성화는 모두 **SETUP 짧게**
5. OLED 에 **기기 고유 8자리 페어링 코드 + QR** 표시 — discriminator/passcode 를 **eFuse MAC 에서 산출**하므로 **기기마다 다르다**(`efuse_commissionable.cpp`, fctry 플래시 불필요). **128×64 / 64×128 패널은 좌측 PIN(`XXXX-XXX-XXXX`) + 우측 QR 병기**, 72×40 은 PIN 만 표시.
6. **SmartThings 앱** → **+** → **디바이스** → **Matter 디바이스 추가** → **OLED 의 QR 스캔**(또는 화면의 수동 코드 입력). 코드가 기기마다 고유라 **여러 대를 동시에 페어링해도 충돌 없음**.
7. SmartThings 가 BLE 로 ESP32 연결 → **Thread network credential 전송** → 802.15.4 mesh 가입
8. Matter Fabric join → 블라인드 엔드포인트 자동 등록 (C6 = 8개 EP1~EP8, **ESP32-H2 = 3개** EP1~EP3 — H2 는 메모리 한계로 축소)

> 🔹 **ESP32-H2(composed) — SmartThings custom 드라이버 필요**: H2 는 RAM 절약을 위해
> composed 구조(root 직속 WindowCovering)라, SmartThings **스톡 드라이버로는 블라인드가 1개만**
> 보인다. `smartthings-driver/` custom Edge driver 를 설치해야 **1카드 3-component**(블라인드 3개)로
> 노출된다. 설치 절차(`edge:drivers:package`→`channels:create`→`assign`→`enroll`→`install`)는
> 루트 [`README.md` §보드별 펌웨어 기능 차이](../README.md#esp32-h2--smartthings-custom-edge-driver-설치)
> 또는 [`smartthings-driver/README.md`](../smartthings-driver/README.md) 참고. (C6 는 Bridge 라 스톡
> 드라이버로 자동 노출 — 설치 불필요. Apple/Google Home 은 H2 도 추가 작업 없이 3개 노출.)

> 페어링 화면 나가기: **로터리 클릭(STOP) 짧게 = 메뉴 / 2초 = 메인**. (Matter Pair 에서 SETUP 짧게 = 페어링 준비 READY 확정)

### Thread credential 재설정 (v3.1 신규)

설정 메뉴에서 `> Thread Rst` 선택 → Yes 확인 → NVS 의 Thread credential 삭제 후 재부팅 → 다시 BLE advertising 시작.

### 재페어링 / 전체 NVS 초기화

```powershell
# 전체 flash 삭제 후 재플래시 (Port 는 보드별: COM3 등)
.\build.ps1 -Board gnpe-c6 -Action erase -Port COM3
.\build.ps1 -Board gnpe-c6 -Action flash -Port COM3
```

> ⚠️ `erase` 는 **전체 flash 삭제** → `rollcode` 파티션(롤링코드 영속)까지
> 지워져 블라인드 **재-PROG** 가 필요하다. 단순 네트워크 초기화는 위 `Thread Rst`
> (Matter factory reset, 기본 NVS 만 삭제 → 롤링코드는 `rollcode` 파티션에 보존)
> 를 쓰는 게 낫다.
> 블라인드 **주소**는 eFuse MAC 산출이라 erase 후에도 동일(기기 고유) — 자세한
> 내용은 루트 `README.md`의 "기기 고유 ID & 롤링코드 영속" 참고.

---

## 9단계: SmartThings 앱에서 블라인드 제어

| SmartThings 명령 | Somfy RTS 커맨드 | 동작 |
|---|---|---|
| Open (100%) | UP (0x2) | 블라인드 완전히 올리기 |
| Close (0%) | DOWN (0x4) | 블라인드 완전히 내리기 |
| Pause / Stop | MY (0x1) | 현재 위치에서 정지 |
| Lift % 설정 | UP/DOWN | 직접 위치 제어 (Somfy는 절대위치 미지원) |
| 루틴 설정 | SmartThings 자동화 | 시간/센서 트리거 → 각 엔드포인트 개별 설정 가능 |

---

## 10단계: 물리 버튼 / 로터리 / 진동 사용법

| 조작 | 동작 |
|---|---|
| UP 버튼 (SW1) | 선택된 블라인드 올리기 (누르는 동안 반복 전송) |
| DOWN 버튼 (SW2) | 선택된 블라인드 내리기 |
| **SELECT 버튼 (SW3)** | **블라인드 선택 순환** (C6 1→…→5→ALL / **H2 1→2→3→ALL**) / 주파수 편집 종료 |
| **LEFT / RIGHT 버튼** (PCF8575, 선택) | 메인: 블라인드 **이전 / 다음** 선택 · 시간/날짜 편집: 자리 이동 · 주파수 편집: 디지트 커서 좌/우 (UP/DOWN=그 자리 값 ±) |
| PROG 버튼 (SW4) 클릭 | Somfy PROG 커맨드 |
| PROG 버튼 (SW4) 2초 롱프레스 | Somfy 리모컨 PROG 명령 (블라인드 등록) |
| **SETUP 버튼 (SW6) 짧게 클릭** (메인 화면, v3.9) | **설정 메뉴 진입** (`> Cancel / Freq Edit / Time Set / Matter Pair / Thread Rst / FW Update`) |
| **SETUP 버튼 짧게 클릭 (설정 메뉴 안에서)** | 커서 위치의 항목 활성화 (예: Matter Pair 시작). SELECT 는 설정 모드에서 무시됨 — 항목 활성화는 **반드시 SETUP 짧게** |
| **SETUP 짧게 또는 2초 (Freq/Time 편집 중)** | 변경 **저장** 후 복귀 (v3.9: 짧게도 저장) |
| **로터리 클릭(STOP) (편집/페어링/리셋 화면)** | 변경 **취소**·화면 종료 → 짧게=메뉴 / 길게=메인 (v3.9) |
| SETUP 버튼 2초 롱프레스 (Thread Rst 확인) | Thread credential 삭제 + 재커미셔닝 |
| 보조 STOP 버튼 (SW5, `_v2`만) | ROT_BTN과 wired-OR (로터리 클릭과 동일 동작) |
| 로터리 CW 회전 | 틸팅 UP (틸트 모션 — 3장 블라인드 슬랫 상하 모션, v3.6) (주파수 편집 중: +0.01 MHz) |
| 로터리 CCW 회전 | 틸팅 DOWN (주파수 편집 중: −0.01 MHz) |
| **로터리 클릭** | **STOP / MY 커맨드** (정지) |
| **모션 중 SELECT (v3.6)** | **모션 중단 + 블라인드 선택 순환 동시 실행** |
| **진동 감지 (`_v2`/`_h2`)** | **흔들면 sleep에서 wake** (0.5초 디바운스) |
| 디바이스 거꾸로 들기 | OLED 화면이 180° 회전 모드로 표시되어 정상 가독 |

> **2026-04-26 변경**: 기존 SW3 = STOP은 SELECT로, STOP은 로터리 클릭으로 이동.

---

## 11단계: 주파수 미세조정 (v3.5 변경 — 설정 메뉴 경유)

1. 블라인드가 반응하지 않을 때 **SETUP 버튼 (SW6) 짧게 클릭** → 설정 메뉴
2. OLED 에 설정 메뉴 표시 (`> Cancel / Freq Edit / Time Set / Matter Pair / Thread Rst / FW Update`)
3. 로터리로 `> Freq Edit` 선택 후 **SETUP 짧게 클릭** → 주파수 편집 화면 진입
4. 로터리 CW/CCW 로 ±0.01 MHz 단위 조정
5. 범위: 447.20 ~ 447.79 MHz (저장값은 **재부팅 후 유지** — 부팅 시 이 범위 밖 손상값만 기본으로 보정)
6. **SETUP 짧게**(또는 2초 길게) → 저장 후 메뉴 복귀 (v3.9). SELECT 는 설정 모드에서 무시됨

> v3.4 이전의 "로터리 2초 롱프레스 = 주파수 편집" 동작은 v3.5 에서 제거되었습니다 (설정 메뉴로 일원화).

---

## 12단계: 배터리 사용 (배터리 변형만)

### USB 충전
1. USB-C 케이블 연결 → MCP73831이 자동으로 300 mA 충전 시작
2. LED1 점등 → 충전 중 표시
3. **OLED 충전 애니메이션**: 매 1분마다 6초간 다이내믹 배터리 차징 영상 표시
   > ⚠ 현 시제품 **H2·xiao 기판**은 BAT_ADC↔CHG_STAT 핀 swap 으로 USB(충전) 감지가 GP12/GPIO17 에서
   > 안 잡혀 충전 애니메이션이 비활성 — 화면 우상단 **`USB`/`BAT`/`LOW` 상태**로 대체된다(`BOARD_BAT_SWAPPED=1`).
4. 풀 충전: 약 2.5시간 (600 mAh, 0.5C)
5. 케이블 분리 시 자동으로 배터리 모드 전환 (D1 Schottky 전원경로)

### 절전 모드 (v3.2 / v3.3)

**전원에 따른 정책 분기 (v3.2):**
- **USB 연결 (충전 중)**: 3 분 무조작 → 화면 보호기 (sleep 진입 안 함)
- **배터리 단독**: 1 분 무조작 → light sleep 진입

**Thread SED + ICD + PM auto-light-sleep (v3.3):**
- `esp_pm_configure()` + `CONFIG_FREERTOS_USE_TICKLESS_IDLE` + `CONFIG_ENABLE_ICD_SERVER` 조합으로
  **라디오를 끄지 않은 채** CPU 만 자동 light sleep.
- Thread mesh 의 ICD poll (SlowPoll 7 s / FastPoll 200 ms) 주기 내 SmartThings 명령 수신 가능 → 즉시 wake + 모션 표시 (v3.6).
- 주변장치 power-down 비활성: I²C/SPI/RMT 상태 보존 (peripheral light-sleep 시 깨어나면 재초기화 불필요).

> ### ★★★2026-08-15 — light sleep 은 **오랫동안 한 번도 진입하지 않았다**
>
> `CONFIG_PM_PROFILING=y` + 콘솔 `pm`(`esp_pm_dump_locks`)으로 계측한 결과:
>
> ```
> bt        APB_FREQ_MAX  Active=1  100%      ← BLE 스택
> rmt_0_0   CPU_FREQ_MAX  Active=1  100%      ← 우리 CC1101 RMT 채널
> Mode stats:  CPU_MAX 160M  99%              ← light sleep 항목 자체가 없음
> ```
>
> PM 락 두 개가 부팅부터 100% 잡혀 있어 automatic light sleep 이 **진입 자체를 못 했다**.
> `esp_pm_configure()` 성공 = "허용됨" 일 뿐 **자고 있다는 증거가 아니다**.
>
> **해제 방법 (적용 완료)**
> - `rmt_enable()` 은 CPU_FREQ_MAX 락을 잡는다 → 부팅 때 켜두지 말고 **송신 burst 동안만**
>   켠다(`_rmt_acquire`/`_rmt_release`). `rmt_disable` 은 진행 중 전송을 자르므로
>   `rmt_tx_wait_all_done()` 로 먼저 비울 것. → CPU_MAX **99% → 5%**
> - `CONFIG_USE_BLE_ONLY_FOR_COMMISSIONING=y` (CHIP 기본값인데 꺼져 있었다) → 등록 후
>   BLE deinit, 이미 provisioned 면 부팅 시 초기화조차 안 함. → `bt` 락 소멸, 힙 **164→184 KB**
>
> **USB 에서는 확인 불가** — USB-JTAG 보호를 위해 설계상 USB 중엔 light sleep 을 끈다
> (`ls = want_ls && !on_usb`). 진입 여부는 **배터리에서만** 보인다.
>
> **계측은 NVS 로 남긴다** — 이 보드는 **포트를 여는 순간 리셋**되므로 RAM 통계는
> 읽으러 가는 행위가 지워버린다. `CONFIG_PM_LIGHT_SLEEP_CALLBACKS=y` + exit 콜백의
> 실제 `sleep_time_us` 를 배터리 로그 행(`bat_sample_t.ls`)에 실어 `bl` 로 조회한다.

**Wake 소스:**
- 4 개 버튼 GPIO — ~~PCF8574 `~INT`~~ **사용 불가**(아래 ★) → **폴링**으로 처리
- 로터리/충전/진동 변화 (PCF8574 P0~P3 + CHG_STAT + VIBE)
- **SmartThings Matter 명령 (v3.6)** — Thread mesh ICD wake 후 해당 모션 즉시 화면 표시

> ★ **PCF8574/8575 `~INT` 는 이 기판에서 쓸 수 없다 (2026-08-13 실측 확정).**
> 버튼을 조작하며 290,023 표본을 관찰했으나 **전이 0회**(HIGH 100%). 회로도상 풀업
> `R3 10k` 는 정상 존재하고, `intpd` 진단(GPIO2 내부 풀다운 + ADC 실전압)에서
> 풀다운 시 2508 mV → 상단 풀업 ≈14 k 로 환산되어 **R3 가 GPIO2 에서 보인다**
> = 배선·GPIO 정상. 고장은 **R3 ~ U3 pad1 구간**(0.65 mm SSOP pad1 냉납 또는 IC INT
> 출력 불량). ※`~INT` ISR 을 등록해두면 초당 ~4,500 회 폭주해 **버튼이 통째로 죽는다**.

### 진동 wake (`_v2`/`_h2`만)
- 디바이스를 흔들면 VS1 진동 센서 동작 → PCF8574 INT pulse → wake
- 0.5초 디바운스 후 진동으로 분류 (실제 버튼 누름 = >100ms 지속)
- **지속 진동 시** (계속 흔드는 경우): 마지막 진동 후 5초간 sleep 차단

---

## 진단 콘솔 (USB 시리얼, 115200)

USB-Serial-JTAG 콘솔로 기기를 직접 조회·조작할 수 있다.

| 명령 | 용도 |
|---|---|
| `bl` / `bl clear` | 배터리 방전 기록(NVS) — 전압·%·평균전류·**light sleep 비율**·ADC 산포 |
| `pm` | `esp_pm_dump_locks` — PM 락 보유 + 절전모드 체류 (진단 빌드 전용) |
| `bd` / `bd clear` | 부팅 진단 — 직전/실패 부팅 단계·리셋 사유 |
| `vl` / `vl clear` | 진동센서 기록 |
| `tx <cmd> [hold_ms]` | RF 송신 — `up`/`down`/`updown`/`myup`/`mydown`/`my`/`prog` |
| `tx8 <hex> [cmd] [hold]` | **raw byte8 강제 지정** 송신 — rtl_433 표시값과의 대응표 작성용 |
| `sel <n>` / `cyc ±1` | 블라인드 선택 / 순환 |
| `freq [idx mhz]` | 주파수 조회·설정 |
| `intpd` | `~INT` 풀다운 진단 — 배선 단선 vs PCF 측 고장 판별 |
| `intdiag` | `~INT` 선 관찰 (15초, 그동안 버튼 조작 필요) |
| `usbsim off\|on` | 배터리 모드 시뮬 |
| `reboot` | 재부팅 |

> ### ★시리얼 접속 시 지뢰 두 개
>
> 1. **`write_timeout` 을 반드시 설정할 것.** 안 하면 write 가 hang 한다.
>    ```python
>    sp = serial.Serial(); sp.port='COM7'; sp.baudrate=115200
>    sp.timeout=0.3; sp.write_timeout=5      # ★
>    sp.open()
>    ```
>    write 가 실패하면 **연결을 새로 만들어 재시도**하면 대개 통한다.
>
> 2. **포트를 여는 것만으로 기기가 리셋된다**(부팅 진단에 `리셋사유=USB리셋(플래시/포트열기)`).
>    → **RAM 에만 있는 통계는 읽으러 가는 순간 사라진다.** 배터리 방전 기록은
>    NVS 라 살아남지만 `pm` 의 누적 통계는 날아간다. 그래서 light sleep 비율을
>    배터리 로그 행에 실어 NVS 로 남기게 만들었다(`bl` 의 `sleep%`).

## 문제 해결

| 증상 | 원인 | 해결 방법 |
|---|---|---|
| CC1101 인식 안됨 | 배선 오류 / 5V 연결 / 구 핀 사용 | **GNPE 검증 핀: SCK=IO6, MOSI=IO7, MISO=IO2, CSN=IO4, GDO0=IO8**(`gnpe-c6.h`). 반드시 3.3V. 다른 보드는 해당 배선도 |
| PCF8574 NACK 실패 | SDA/SCL 배선 / pull-up 미장착 | GNPE: **SDA=IO19, SCL=IO18**(bit-bang) + 4.7kΩ pull-up to 3V3 필수. (H2 는 OLED 와 공유 HW I2C — `BOARD_I2C_SHARED`) |
| `CONFLICT! driver_ng vs old driver` abort | legacy/new I2C 동시 링크 | `CONFIG_LEGACY_DRIVER` 비활성화 (모두 new 드라이버) |
| OLED 절반만 표시 / 글자 너무 큼 | (GNPE 72×40) SSD1315 보정 누락 | `BOARD_OLED_FIXUP_72X40=1` + `CONFIG_OFFSETX=28` + multiplex(0xA8 0x27)/COM(0xDA 0x12). **128×64 패널은 보정 끔**(`FIXUP=0`, `OFFSETX=0`) |
| OLED 내용이 한쪽으로 쏠림 | 패널 크기 ≠ `BOARD_OLED_*` | 보드 헤더의 `BOARD_OLED_WIDTH/HEIGHT` 와 `sdkconfig` 의 `CONFIG_OFFSETX` 를 실제 패널에 맞출 것 |
| OLED 상하 반전(뒤집힘) | H2 시제품 패널 180° 장착 + `-Rotate` 미지정(기본 `ROTATE_180=0`) | `-Rotate 180` 로 빌드/플래시 (`.\build.ps1 -Board esp32-h2 -Rotate 180 -Action flash`). 좌우(거울) 반전이면 `-Rotate m0` |
| 로터리 미반응 | PCF8574 I2C 미연결 | GNPE: SDA=IO19, SCL=IO18 bit-bang + 4.7kΩ pull-up 확인 |
| 블라인드 반응 없음 | 주파수 불일치 | 로터리 롱프레스 → 주파수 미세조정 |
| **PROG 를 길게 눌러도 반응 없음** (짧게는 정상) | `_build_frame` 이 byte7 을 전 프레임 `0x84` 로 고정. 정품·ESPSomfy 는 **재전송마다 `196+rep*4`** 로 올린다 | 2026-08-15 수정 완료 — 송신 루프에서 프레임마다 갱신(byte9 체크섬도 재계산). 되돌리려면 `frame[7] = 0x84;` |
| SDR 로 보면 한 번 눌렀는데 신호가 여러 번 잡힘 | 프레임 수가 정품(2개)보다 많거나, 프레임 간 무신호가 길어 rtl_433 이 별개 버스트로 분리 | `SOMFY_REPEAT_COUNT=2` + `_transmit_frame` 대기 `us/1000`(내림). 정품 interFrame ≈3.9 ms 수준이면 한 버스트로 묶인다 |
| OLED 안 켜짐 | I2C 주소 불일치 | `CFG_OLED_ADDR=0x3C` 확인 |
| Matter 페어링 실패 | Thread Border Router 부재 / 거리 | SmartThings Hub v3+ / Apple TV 4K / Nest Hub 2nd gen 등이 같은 네트워크에 있는지 확인 |
| Matter 페어링 실패 (코드 인식) | NVS 의 이전 fabric 잔존 | 설정 메뉴 → Thread Rst, 또는 `.\build.ps1 -Action erase` |
| SmartThings 명령에 응답 지연 (≤7초) | Thread SED SlowPoll 주기 (`CONFIG_ICD_SLOW_POLL_INTERVAL_MS=7000`) | 정상 동작 — ICD 응답성 (FastPoll 200 ms) 는 active 트랜잭션 중에만 발동 |
| **SmartThings 에서 offline 로 뜨고 안 돌아옴** | `CONFIG_ICD_IDLE_MODE_INTERVAL_SEC` 가 esp-matter 기본값 2 → CHIP 이 구독 최대주기를 이 값으로 협상해 **2초마다 보고를 강요**당한다(실측: IM:ReportData 2.02초 간격 무한 반복). 배터리로 돌리면 그 약속을 못 지켜 허브가 offline 판정 | **30 으로 상향**(적용 완료). 하향 링크 지연은 SlowPoll 이 정하므로 명령 반응은 그대로 |
| 리셋 직후 시간 초기화 | NVS 시간 영속화 미동작 | v3.6 이상 펌웨어 사용 + border router 통한 SNTP 동기화 1시간 대기 |
| 빌드 실패 (MSYSTEM) | Git Bash 사용 | PowerShell에서 `build.ps1` 실행 |
| 롤링코드 오류 (모터 무응답) | 전체 `erase-flash` 로 `rollcode` 파티션까지 삭제 | 블라인드 재-PROG. (Matter factory reset/OTA 는 `rollcode` 파티션 보존 → 재등록 불필요) |
| 여러 기기가 같은 블라인드 충돌 | (구 펌웨어) 하드코딩 주소 동일 | 현 펌웨어는 eFuse MAC 산출로 기기별 고유 — 각 기기 재플래시 후 PROG 재등록 |
| 펌웨어 업데이트 안 됨 | OTA 이미지 PID/버전 불일치 | 대상 보드 PID + 현재보다 높은 버전으로 `.ota` 생성(`doc/OTA.md`) |
| 바이너리 크기 초과 | 파티션 너무 작음 | `partitions.csv`에서 파티션 크기 확인 |

---

## 참조 링크

| 항목 | URL |
|---|-----|
| ESP-IDF **v5.4.1** | https://docs.espressif.com/projects/esp-idf |
| esp-matter (`7706cfbd` · main) | https://github.com/espressif/esp-matter |
| esp-idf-ssd1306 (`554df45` · master) | https://github.com/nopnop2002/esp-idf-ssd1306 |
| esp_qrcode **0.2.0** (관리 컴포넌트) | https://components.espressif.com/components/espressif/qrcode |
| Somfy RTS 프로토콜 | https://pushstack.wordpress.com/somfy-rts-protocol/ |
| CC1101 모듈 매뉴얼 (E07-M1101D-SMA) | [`doc/CC1101/E07 (M1101D-SMA)/E07-M1101D-SMA_Usermanual_EN_v1.30.pdf`](<./CC1101/E07 (M1101D-SMA)/E07-M1101D-SMA_Usermanual_EN_v1.30.pdf>) |
| CC1101 모듈 핀맵 이미지 | [`doc/CC1101/E07 (M1101D-SMA)/M07-M1101D_MAPPING.jpg`](<./CC1101/E07 (M1101D-SMA)/M07-M1101D_MAPPING.jpg>) |
| PCF8574 데이터시트 | https://www.ti.com/lit/ds/symlink/pcf8574.pdf |
| ESP32-C6-0.42 보드 문서 (GNPE) | [`doc/esp32/GNPE/ESP32-C6-0.42/0.42-ESP32C6.pdf`](<./esp32/GNPE/ESP32-C6-0.42/0.42-ESP32C6.pdf>) |
| ESP32-C6-0.42 핀맵 이미지 | [`doc/esp32/GNPE/ESP32-C6-0.42/GNPE_ESP32-C6-0.42_MAPPING.png`](<./esp32/GNPE/ESP32-C6-0.42/GNPE_ESP32-C6-0.42_MAPPING.png>) |

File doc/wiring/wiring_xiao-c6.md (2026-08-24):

# 배선도 — Seeed XIAO ESP32-C6

> **보드 핀맵 단일 진실원천: [`main/boards/xiao-c6.h`](../../main/boards/xiao-c6.h)**
> 핀 출처: `doc/esp32/XIAO/XIAO_ESP32C6_Pinout.xlsx`("QFN32 Pin Summary") +
> `Xiao esp32-c6.png`(앞/뒷면) + `XIAO_ESP32_C6_v1.0_SCH_260114.pdf` (Seeed 공식).

- **브랜드/제품**: Seeed Studio "XIAO ESP32-C6"
- **SoC / IDF target**: ESP32-C6 (GNPE 와 동일 SoC) / `esp32c6`
- **Matter Product ID**: `0x8003` (GNPE 0x8000 과 구분 — 같은 SoC 라 OTA 는 PID 로만 구분)
- **OLED**: XIAO 에 내장 OLED 없음 → **외부 0.96" SSD1306 128×64** (I2C 0x3C). 현 시제품 기판은 **180° 회전 장착** → 빌드 시 `-Rotate 180`
- **첫 빌드 전 1회**: `./build.ps1 -Board xiao-c6 -Action set-target`
- **빌드**: `./build.ps1 -Board xiao-c6 -Action build -Rotate 180` — 현 시제품 기판은 OLED 가 **180° 장착**이라 `-Rotate 180` 필수(flash·ota-image 도 동일)

## 핀맵 이미지 (앞/뒷면)

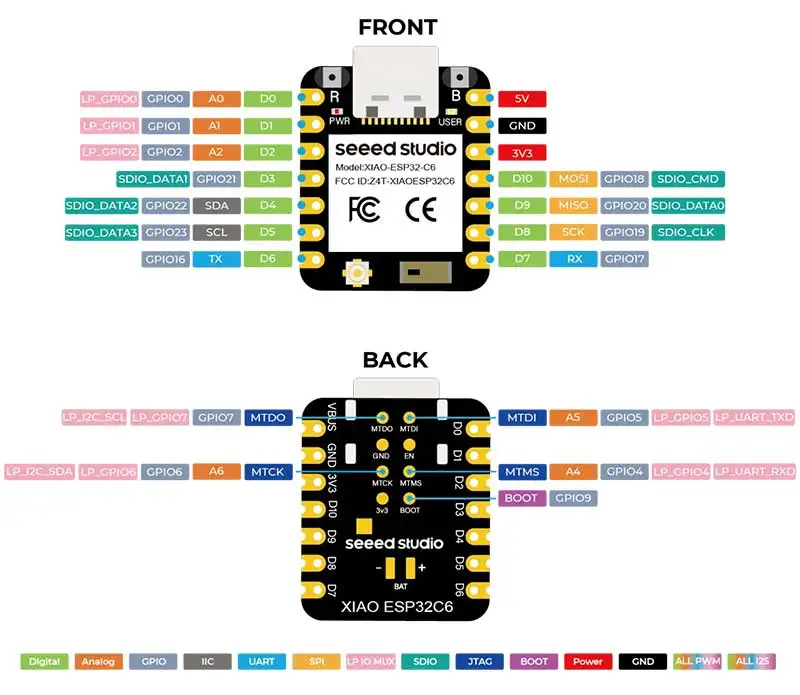
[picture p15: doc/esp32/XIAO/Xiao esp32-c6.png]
Seeed XIAO ESP32-C6 핀맵 (앞/뒷면)


> 앞면 11 castellated + 뒷면 패드(MTCK/MTDO=LP_I2C 등). 최종 기준은 아래 표
> (=`boards/xiao-c6.h`). **D11(GPIO3)은 미노출** 주의(이미지 라벨과 별개로 보드 미연결).

## CC1101 모듈 (E07-M1101D-SMA) 핀맵

E07-M1101D-SMA 핀맵

> ※ **제작 보드는 E07-400MM10S 모듈** 사용 — 같은 CC1101 칩이라 핀맵은 동일하나, 크리스털 오차가
>   달라 register **447.70** → on-air 447.673 MHz(실제 블라인드 인식 확인). 테스트용 E07-M1101D-SMA 는
>   447.72 → 447.675. 주파수 상세는 README "RF / Somfy RTS 447" 섹션 참고.

## XIAO 패드 ↔ GPIO (앞면 11 edge + 뒷면 패드)

```
[앞면 edge — 11 castellated]
D0=GPIO0(A0,LP)  D1=GPIO1(A1,LP)  D2=GPIO2(A2,FSPIQ,LP)  D3=GPIO21
D4=GPIO22(SDA)   D5=GPIO23(SCL)   D6=GPIO16(TX)          D7=GPIO17(RX)
D8=GPIO19(SCK)   D9=GPIO20(MISO)  D10=GPIO18(MOSI)

[뒷면 패드 — 노출 확인된 것]
MTCK=GPIO6 (A6, LP_GPIO6, LP_I2C_SDA, FSPICLK)   ← 하드웨어 LP_I2C
MTDO=GPIO7 (    LP_GPIO7, LP_I2C_SCL, FSPID)     ← 하드웨어 LP_I2C
```

> 📌 **노출 정정(보드 실물 기준)**
> - **D11=GPIO3(A3) 은 브레이크아웃되지 않음 → 사용 불가.** (칩 핀에는 존재하나
>   XIAO 보드가 패드로 빼지 않음.) 이전에 VIBE 를 GPIO3 에 뒀던 것을 **D0(GPIO0)** 로 옮김.
> - 뒷면 **MTCK=GPIO6=`LP_I2C_SDA`, MTDO=GPIO7=`LP_I2C_SCL`** 는 하드웨어 LP_I2C
>   전용핀 → PCF8574 를 여기 두면 부팅 자동 폴백이 우선 사용(미연결 시 공유로 전환).
> - GPIO8 미노출. MTMS=GPIO4·MTDI=GPIO5 의 뒷면 노출 여부는 미확인 → **사용하지 않음**.
> - **확정 가용핀 = 앞면 D0~D10(11) + 뒷면 MTCK/MTDO(2) = 13** (프로젝트 12핀 사용).

## 핀 매핑 (요약)

| 기능 | 신호 | 패드 | GPIO | 비고 |
|---|---|---|---|---|
| CC1101 | SCK  | D8  | **GPIO19** | FSPICLK, GPIO-matrix 라우팅 |
| CC1101 | MISO | D9  | **GPIO20** | FSPIQ |
| CC1101 | MOSI | D10 | **GPIO18** | FSPID |
| CC1101 | CS | D3  | **GPIO21** | (FSPICS0) active-LOW |
| CC1101 | GD0  | D6  | **GPIO16** | RMT 비동기 TX 데이터 |
| OLED | SDA  | D4  | **GPIO22** | XIAO 기본 I2C — 0.96" SSD1306 128×64 |
| OLED | SCL  | D5  | **GPIO23** | I2C 0x3C |
| PCF8574 | SDA | D4(공유)/MTCK | **GPIO22** / 6 | 자동 폴백 — LP_I2C(6) 우선 프로브 → 무응답 시 공유 OLED 버스(22) |
| PCF8574 | SCL | D5(공유)/MTDO | **GPIO23** / 7 | 〃 pull-up: 공유=OLED 공통 1쌍 / LP=PCF 전용 1쌍 |
| PCF8574 | ~INT | D2 | **GPIO2** (LP) | active-LOW wake, 10 kΩ pull-up — **★현 기판에서 동작 안 함(아래)** |
| 센서 | CHG_STAT | D7 | **GPIO17** | **USB 감지** — VBUS 분압 active-HIGH (충전 섹션) |
| 센서 | BAT ADC | D1 | **GPIO1** (A1) | 배터리 전압 분압 ADC → 실측 % (충전 섹션) |
| 센서 | VIBE | D0 | **GPIO0** (LP) | VS1 진동, light-sleep wake (구 GPIO3/D11 미노출) |

> **PCF8574 배선 — 런타임 자동 폴백 (`BOARD_I2C_LP_FALLBACK=1`):** 부팅 시 펌웨어가
> **LP_I2C(뒷면 MTCK=GPIO6 / MTDO=GPIO7, bit-bang)** 에서 PCF8574(0x20)를 먼저 프로브하고,
> **무응답이면 공유 HW I2C(D4/D5=GPIO22/23, OLED 버스)** 로 자동 전환한다. → 어느 쪽에
> 배선해도 같은 펌웨어로 동작(택1·재빌드 불필요).
> - **공유(앞면 D4/D5)**: 납땜 쉬움, 외부 4.7 kΩ pull-up 은 OLED·PCF **공통 1쌍(저항 2개)**. 뒷면 작업 불요.
> - **LP_I2C(뒷면 MTCK/MTDO)**: ⚠️ **이 구성은 풀업이 총 2쌍(저항 4개) 필요하다.**
>   OLED 는 **언제나** 앞면 D4/D5(GPIO22/23)에 붙으므로 "D4/D5 를 비운다"는 성립하지 않고,
>   PCF 를 LP 로 빼는 순간 **I2C 버스가 물리적으로 둘로 분리**된다 → **버스마다 1쌍씩** 필요:
>     · **OLED 버스(D4/D5=GPIO22/23) 전용 4.7 kΩ 1쌍 → +3V3**
>     · **PCF 버스(MTCK/MTDO=GPIO6/7) 전용 4.7 kΩ 1쌍 → +3V3**
>   ※ 그리고 **OLED VCC 옆 100 nF 디커플링 1개**도 같이 둘 것.
>
> 🔴 **실기 사고 기록(2026-07-16)**: 이 문서가 위 "OLED 버스 전용 1쌍"을 명시하지 않아,
>   PCF 쪽에만 풀업을 단 기판이 제작됐다. 결과 — OLED 버스에 **ESP32 내부 풀업(~45 kΩ)만**
>   남았고, 배선 용량 ~200 pF 기준 τ≈9 µs·VIH(2.3 V) 도달 ≈10.7 µs 라 **400 kHz(비트주기
>   2.5 µs)는 물론 100 kHz(10 µs)에서도 상승시간이 모자란다.** 증상: OLED 가 I2C 프로브에
>   **응답조차 못 함(화면 안 켜짐)** / 어쩌다 붙어도 **INVALID_STATE 폭주 → 찌그러짐·멈춤**.
>   → **내부 풀업으로는 어떤 속도로도 못 쓴다. 외부 4.7 kΩ 는 선택이 아니라 필수.**
>
> ⚠️ **JTAG**: 자동 폴백이 부팅 프로브로 GPIO6/7 을 GPIO 로 잡으므로, 공유 배선이라도
> **MTCK/MTDO JTAG 디버그는 불가**. JTAG 가 꼭 필요하면 `BOARD_I2C_LP_FALLBACK=0` +
> 공유 단독(`BOARD_I2C_SHARED=1`)으로 빌드. 앞면 **D1(GPIO1)=BAT ADC** 는 그대로.

## PCF8574 (I2C addr 0x20, bit-bang)

`A0/A1/A2 → GND` (주소 0x20). 8개 P-핀은 회로 고정:

| P-핀 | 연결 | 기능 |
|---|---|---|
| P0 | ROT_A | 로터리 CW/CCW |
| P1 | ROT_B | 로터리 CW/CCW |
| P2 | ROT_BTN | 클릭=STOP/MY (주파수 편집은 설정 메뉴 `Freq Edit` — v3.5 이후) |
| P3 | SW6 SETUP | 짧게=설정 메뉴, 2초=메뉴 항목 저장/실행 |
| P4 | SW1 UP | 블라인드 ↑ |
| P5 | SW2 DOWN | 블라인드 ↓ |
| P6 | SW3 SELECT | 블라인드 선택 순환 |
| P7 | SW4 PROG | Somfy PROG (2초 롱프레스=모터 등록) |

> 🔁 **로터리 = EC05 (하프스텝)** — 디텐트가 `11`·`00` **양쪽**(2디텐트/사이클)이라
> `boards/xiao-c6.h` 에 **`BOARD_ROT_HALF_STEP=1`** 설정 → 그레이코드 LUT 누산 디코더
> (바운스 상쇄·양방향 대칭). GNPE 의 **EC11(full-step, rest@11)** 과 디코더가 다르다.
> 방향이 반대로 느껴지면 `button_handler.h` 의 `_ROT_CW_ON_AB1` 를 뒤집는다.

## ⚠️ 사용 금지/주의 핀

| GPIO | 용도 | 주의 |
|---|---|---|
| **GPIO14** | 온보드 **RF 스위치(ANT1/ANT2)** | **절대 사용 금지** — C6 내장 라디오 안테나 선택, Thread/BLE RF 에 영향 |
| GPIO15 | USER LED | 사용 시 LED 와 충돌 |
| GPIO9  | BOOT (strapping) | 부팅 영향 |
| GPIO12/13 | USB D-/D+ | USB 사용 시 금지 |
| **GPIO3 (D11)** | 미노출 | XIAO 보드가 패드로 빼지 않음 → **사용 불가** |
| GPIO8 | 미노출 | 사용 불가 |
| **GPIO4/5 (MTMS/MTDI)** | 뒷면 TP 노출되나 **회피** | Seeed 스키매틱 명시 *"Avoid using GPIO4, 5, 8, 9, 15"* (VDDA3P3 인접) |

> ✅ MTCK=GPIO6·MTDO=GPIO7(=LP_I2C)은 위 회피목록에 **없음** → PCF8574 LP_I2C(비트뱅) 용
> OK. 자동 폴백이 부팅 시 이 핀을 프로브하므로 JTAG 와는 양립 불가(위 PCF 배선 주석 참고).

> CC1101 SPI 는 FSPI 네이티브(FSPICLK/D=GPIO6/7) 대신 D8/D9/D10(GPIO-matrix) 사용 —
> GPIO6/7 은 PCF8574 LP_I2C(자동 폴백 프로브) 전용. CC1101 은 저속이라 matrix 라우팅으로 충분.

## 🔋 배터리 / 충전 (XIAO 온보드 — 외부 충전회로 불필요)

> 출처: XIAO ESP32-C6 공식 스키매틱 `XIAO_ESP32_C6_v1.0_SCH_260114.pdf` (03 Power).

**GNPE 와 가장 큰 차이**: XIAO 는 충전·파워패스가 **이미 보드에 내장**되어 있어,
**BAT+/BAT- 패드에 단셀 LiPo 를 직결**하기만 하면 된다. GNPE 처럼 외장 충전회로
(MCP73831 + SS14 + 충전저항 + 충전 LED)를 추가할 필요가 **전혀 없다**.

| 항목 | XIAO 온보드 | 비고 |
|---|---|---|
| 충전 IC | **SGM40567-4.2** | 단셀 LiPo, 4.2V 컷오프 |
| 충전 전류 | **120 mA** | R10=200K, `ICharge=24000/200K` (GNPE MCP73831 ~300mA 보다 느림) |
| 파워패스 | USB=USB동작+충전 / 분리=배터리동작 | Q1 P-MOS + D1 Schottky 자동 전환 |
| DC-DC | **SGM6029C** 5V→3.3V | 3V3_OUT 패드로 출력 |
| 노출 패드 | **BAT+/BAT-**, **VBUS(5V)**, 3V3_OUT, GND | 배터리·USB·전원 |

### 충전 감지 — A+B 방식 (펌웨어 구현됨)

충전 IC status `NCHG` 는 **온보드 빨강 LED(CHG1) 전용**(GPIO 미노출)이라 직접 못 읽는다.
대신 분압 2개로 **USB 연결(A) + 배터리 전압(B)** 를 읽어 충전중/만충을 판별한다
(`boards/xiao-c6.h`: `BOARD_CHG_STAT_ACTIVE_HIGH=1` · `BOARD_HAS_BAT_ADC=1`).

| | 분압 배선 | 핀 | 펌웨어 |
|---|---|---|---|
| **A. USB 감지** | VBUS(5V)─100k─◉─150k─GND | ◉ = **D7 (GPIO17)** (~3.0V) | active-HIGH (HIGH=USB) |
| **B. 배터리 전압** | BAT+─100k─◉─100k─GND | ◉ = **D1 (GPIO1=A1)** ADC | ADC→OCV-SoC→실측 % |

- **충전중 vs 만충**: A(USB)=HIGH AND Vbat<~4.15V → **충전중** / A AND Vbat≈4.2V → **만충**.
- 분압비·핀은 `boards/xiao-c6.h` (`BOARD_PIN_BAT_ADC` · `BOARD_BAT_DIV_*`)에서 조정.
- 미사용 시 D7 은 **GND 고정**(floating 금지). 실측 % 는 충전 중 단자전압이라 약간 높게 읽힘(표시용).

#### ★★★2026-08-24 사고 기록 — R5 접촉 불량 (COM7 실기)

**증상**: 잔량 표시가 0% 로 굳거나, 전원 재투입마다 **0% → 10% → 100%** 로 바뀐다.

**측정**:

| | 값 |
|---|---|
| 멀티미터, 배터리 단자 | **4.187V**(USB 분리) / **4.192V**(USB 연결) — 정상 |
| 펌웨어 ADC 환산 | **2,600 mV** (정상값의 62%) |
| 역산한 분압 하단 실효저항 | **45.1 kΩ** (설계 100 kΩ) |

45kΩ 은 **ESP32 내부 풀다운 값과 일치**한다(코드에도 `"내부 풀다운 ~45k"` 진단
항목이 있다 — 전에 CHG_STAT 에서 같은 현상을 겪었다).
⇒ **R5(하단 100k)가 끊긴 채 칩 내부 풀다운만 접지 역할을 하는 상태.**

**소프트웨어 무관 확인**: iot_button 제거/복원 두 빌드에서 2,604 / 2,600mV 로 동일.
마지막 커밋 상태로 되돌려도 동일.

**같은 원인으로 보이는 과거 사건** — 둘 다 NVS 방전기록에 남아 있고, 산포가
1~6카운트로 **깨끗**했다(= ADC 잡음이 아니라 측정 전체가 낮게 나왔다):

```
2026-08-20   4069 → 2651 → 2129 mV   (8시간 걸쳐 3845mV 로 "회복")
2026-08-23   4055 → 3002 mV          (리셋하니 4078mV 로 즉시 정상)
```

접촉이 붙었다 떨어졌다 하면 하단 경로가 R5(100k) ↔ 내부 풀다운(45k)으로 오가며
정확히 이런 값을 만든다.

**조치**: 전원 완전 차단 후 **R5 와 100nF 손납땜 부위 재작업**. 저항 측정으로
100kΩ 확인. 100nF 은 R5 와 **병렬**로 붙이는 자리라 그 작업과 무관하지 않다
(2026-08-19 교체 직후에는 4,010mV·산포 3 으로 정상이었다).

**소프트웨어로 덮지 말 것**: `BOARD_BAT_DIV_BOT` 을 45 로 바꾸면 표시는 맞아지지만
내부 풀다운은 30~60kΩ 로 흔들리고 온도·개체차도 크다. 접촉 불량이면 값이 계속
오락가락한다. 펌웨어에 넣은 **급락 표본 거부**(300mV 초과 낙차를 연속 3회까지 버림,
`sim/tools/bat_spike_reject_sim.py`)는 순간 튐용 안전망일 뿐 **이 결함을 가릴 수 있으므로**
로그(`[BAT%] ★급락 표본 거부`)가 보이면 하드웨어를 의심할 것.

#### ★BAT_ADC 필터 커패시터 (2026-08-12 추가 / 2026-08-19 100nF 로 확정, 필수)

**B 분압의 하단 저항 R5 와 병렬**(= 중간 탭 ↔ GND)에 커패시터를 단다. h4 회로도 기준:

```
BAT+ ──[R4 100K]──┬──[R5 100K]── GND
                  │      ║
               ADC_SW    ╚═[C]═ GND      ← 여기 (R5 와 병렬)
                  │
              [ADC1 DIP SW]
                  │
               BAT_ADC ──→ XIAO GPIO1
```

**상단(R4)과 병렬은 금지** — 배터리 레일 잡음을 ADC 로 그대로 통과시켜 악화된다.
BAT+↔GND 는 무의미(C6/C7/C8 470µF 벌크가 이미 담당).

**왜 필요한가**: 분압 소스 임피던스가 R4∥R5 = **50kΩ** 으로 높아 (a) SAR ADC 의
샘플홀드 커패시터를 샘플링 창 안에 다 못 채우고 (b) 레일 잡음이 그대로 실린다.
실측으로 **배터리 구동 시 한 측정 안 8표본 산포가 중앙값 36카운트(54mV), 최대
115(174mV)** 였다(USB 는 13카운트). 8표본은 수십 us 안에 끝나 같은 순간을 재므로
이건 전압 변동이 아니라 **ADC 교란**이다. 이게 잔량 % 가 튀던 원인이었다.

| 용량 | 시정수 τ(50kΩ) | 차단주파수 | 냉시동 정착(9τ) | 실측 산포 | 판정 |
|---|---|---|---|---|---|
| 없음 | — | — | — | 중앙값 13(USB)/36(배터리) | 잔량 % 튐 |
| **100nF** | **5 ms** | **31.8 Hz** | **45 ms** | **중앙값 3, 최대 5** | ★**채택(2026-08-19)** |
| 10µF | 500 ms | 0.32 Hz | 4.5초 | 중앙값 3, 최대 4 | 동등(과잉) |
| 100µF | 5 초 | 0.032 Hz | **45초** | 중앙값 3, 최대 4 | 과함(아래 함정) |

- **3카운트는 ESP32 SAR ADC 자체의 잡음 바닥**이다. 100nF·10µF·100µF 이 **셋 다 동일한**
  결과라 100nF 보다 키울 이유가 없다.
- ★**100µF 함정**: 9τ=45초라 **배터리를 새로 꽂은 뒤 45초간 값이 낮게 읽히며 상승**한다.
  그런데 `somfy_app.c` 의 방전 중 % 하한(`BAT_FLOOR_MIN_N`=5표본=25초)이 그 낮은 값을
  잡아 **세션 내내 약 4%p 낮게 고정**된다. 100µF 을 쓰려면 `BAT_FLOOR_MIN_N` 을 9(45초)로
  올려야 한다. 10µF 은 9τ=4.5초 < 측정주기 5초라 이 문제가 아예 없다.
- ★**2026-08-19 100nF 으로 교체하고 실측 — 위 판정 기준의 "3~5 = 동등(OK)" 에 정확히
  들어왔다.** COM7 실기 20표본(100초, USB 급전, 무선 ON):
  **산포 중앙값 3·평균 2.6·최대 5, 30카운트 이상 0건**, vbat 4010~4014mV(변동 4mV),
  raw 2001~2003(2카운트). → 잡음원이 실제로 kHz 이상이어서 차단 31.8Hz 로 충분했다.
  10µF(τ=500ms)은 **과잉**이었던 셈이고, 100nF 은 100µF 함정(아래)에서 4자릿수 멀다.
  판정 기준은 향후 재검증에도 그대로 쓴다:
  **3~5 = 동등(OK) / 5~10 = 충분 / 15 이상 = 용량 부족(되돌릴 것)**.
- MLCC 는 **DC 바이어스 감쇠**가 있다 — 6.3V급 X5R 10µF 에 2V 가 걸리면 실효 6~7µF.
  결론은 안 바뀌지만 τ 계산 시 감안할 것. **100nF 급(C0G/X7R 소용량)은 감쇠가 거의
  없어** 이 항목에서도 유리하다.
- 분압 상시 소모는 4.1V/200kΩ = **20.5µA**(15시간에 0.31mAh, 700mAh 의 0.04%) — 무시 가능.
- ⚠️ 같은 행의 **A 분압(R6 100K/R7 150K)에는 붙이지 말 것** — 디지털 레벨 판정이라
  커패시터가 엣지를 뭉갠다.

> ⚠️ 단셀은 **PCM(보호회로) 내장 셀** 사용 권장 — SGM40567 은 충전만 담당하고
> 과방전 보호는 셀 PCM 에 의존한다.

> ⚠️ **현 시제품 기판은 위 A·B 분압이 핀에서 뒤바뀌어 있다**(BAT_ADC핀 **D1/GPIO1 ← VBUS** 100k/150k,
>   CHG_STAT핀 **D7/GPIO17 ← BAT** 100k/100k). GPIO17 은 ADC·아날로그 comparator 불가핀(C6 ADC=GPIO0~6,
>   ana_cmpr 미지원)이라 **배터리 잔량 % 측정이 물리적으로 불가** → `boards/xiao-c6.h` 의
>   **`BOARD_BAT_SWAPPED=1`** 로 화면 우상단에 **`USB`/`BAT`/`LOW` 상태**를 표시한다(GPIO1 의 VBUS 를
>   ADC 로 읽어 USB 감지 + GPIO17 내부풀업 1임계≈3V 로 저전압 판별). 위 **정상 배선(BAT→GPIO1, VBUS→GPIO17)
>   으로 기판을 고치면 `BOARD_BAT_SWAPPED=0`**(기본값) → 기존 충전률 % 표시로 자동 복귀(두 경로 코드 보존).

## 🖥 디스플레이 (GNPE 와 다름)

| 항목 | XIAO | GNPE(참고) |
|---|---|---|
| 패널 | **외부 0.96" SSD1306 128×64** | 내장 0.42" SSD1315 72×40 |
| 방향 | **정방향**(회전 없음) | 거꾸로 장착 → SW 180° 회전 |
| 컬럼 오프셋 | **0** (`CONFIG_OFFSETX=0`) | 28 (SEG28~99) |
| 72×40 보정 | **불필요** | 필요(멀티플렉스/COM/IREF) |
| I2C 주소 | 0x3C | 0x3C |

- 규격은 **`boards/xiao-c6.h` 의 `BOARD_OLED_*`** 가 결정한다(WIDTH=128, HEIGHT=64,
  COL_OFFSET=0, ROTATE_180=0, FIXUP_72X40=0). 오프셋은 `sdkconfig.defaults.xiao_c6`
  의 `CONFIG_OFFSETX=0` 과 짝을 이룬다.
- **렌더러는 해상도로 자동 선택**된다 — 128×64 이므로 **풀스크린 네이티브
  렌더러**(고딕 6×9 폰트 + 7세그먼트 시계)가 적용된다(`oled_ui.h` 의
  `OLED_RENDER_128X64`). 72×40 논리 캔버스가 아니라 128×64 물리 픽셀에 1:1 로
  그린다. 다른 규격 패널을 달면 그 해상도에 맞는 렌더러가 자동으로 선택된다.

## 조립 주의

- CC1101 은 **3.3V 전용** — 5V 금지.
- PCF8574 SDA/SCL: **자동 폴백** — 뒷면 **MTCK/MTDO(GPIO6/7) LP_I2C** 우선, 미연결 시
  앞면 **D4/D5(GPIO22/23)** OLED 공유로 전환. 어느 쪽이든 같은 펌웨어로 동작.
  GPIO14(안테나)·GPIO15(LED)·GPIO12/13(USB)은 건드리지 말 것.
- 외부 풀업: 공유 배선=OLED·PCF 공통 SDA/SCL 각 **4.7 kΩ** 1쌍 / LP_I2C 배선=PCF 전용 별도 1쌍.
  ~INT 는 **10 kΩ** → +3V3.
- CC1101 은 저속이라 GPIO-matrix 라우팅으로 충분.

### ★ `~INT`(GPIO2) 는 현 h4 기판에서 동작하지 않는다 (2026-08-15 실측)

버튼을 조작하며 **290,023 표본**을 관찰했으나 **전이 0회**(HIGH 100%).
콘솔 `intpd` 진단(GPIO2 내부 풀다운 + ADC 실전압)으로 고장 위치를 갈랐다:

```
floating(풀 없음)   디지털=HIGH  ADC=3255 mV
내부 풀다운 ~45k    디지털=HIGH  ADC=2508 mV   ← 상단 풀업 ≈ 14 k 로 환산
내부 풀업   ~45k    디지털=HIGH  ADC=3256 mV
출력 LOW readback = LOW                        ← 싱크 가능, 3V3 단락 아님
```

**R3 10 kΩ 이 GPIO2 에서 그대로 보인다 = 배선·GPIO 모두 정상.**
PCB 네트 추적으로도 `U3 pad1(~INT) ── R3 10k ── +3V3` + `U1 pad3(GPIO2)` 3점 연결이
확인되고 동판 배선도 실재한다(segment 20 / via 2).

⇒ 고장은 **R3 ~ U3 pad1 구간** — 0.65 mm 피치 SSOP **pad 1 냉납** 또는 PCF8575 의
INT(open-drain) 출력 불량. **pad 1 재납땜을 먼저 시도**하고 `intdiag` 로 전이가
잡히는지 확인할 것. GPIO 를 다른 핀으로 옮기는 것은 불필요하다(그쪽은 정상).

> ⚠ `~INT` ISR 을 등록해두면 **초당 약 4,500 회 폭주**(실측 540,522회/120초)해
> prio 10 버튼 태스크를 짓밟아 **버튼이 통째로 죽는다**. 진단용이라도 남기지 말 것.
> 부품·핀 배치는 정상이다 — PCF8574(16핀, INT=pin 13) vs PCF8575(24핀, INT=pin 1)
> 혼동이 원인이 아님을 KiCad 대조로 확인했다(h4 = PCF8575DBR / SSOP-24, pad1 = ~INT).

#### 데이터시트 대조 — 대안 가설이 전부 배제된다

`doc/parts/pcf8575.pdf` (TI PCF8575, §8 Detailed Description / §6 Timing / §5 Electrical) 대조:

| 항목 | 데이터시트 | 우리 | 판정 |
|---|---|---|---|
| INT sink 능력 | `IOL = 1.6 mA @ VOL 0.4 V` | R3 10 kΩ → **0.33 mA** | 여유 5배 → **풀업 값 무관** |
| INT 유효 시간 | **`tiv = 4 µs`** (P port → INT) | intdiag 샘플링 52 µs | 아래 ★ 때문에 무관 |
| 다른 디바이스 트래픽 | *"Reading from or writing to **another device** does not affect the interrupt circuit"* | OLED 가 같은 버스 공유(폴백 모드) | **OLED 간섭 아님** |
| 입력 모드 요구 | *"any rising or falling edge of the port inputs **in the input mode**"* | init 에서 `0xFF 0xFF` write 로 전 핀 입력 래치 | 조건 충족 |

⇒ "풀업 부족 / 짧은 펄스를 놓침 / 공유 버스 간섭" 세 가설이 **전부 배제**된다.

> ★**판정을 결정적으로 만드는 문장**
> *"Resetting and reactivating the interrupt circuit is achieved when **data on the port
> is changed to the original setting**, or data is read from or written to the port"*
>
> 버튼을 **떼면** 포트가 원래 값으로 돌아가 INT 가 **자가 해제**된다. 즉 INT 는
> **누르고 있는 동안 LOW 로 유지**된다(누름 1회당 100 ms 이상, `tiv` 4 µs 라 지연도 무의미).
> 그런데 15초간 **290,023 표본에서 전이 0회**였다 — "짧은 펄스를 놓쳤다" 로는 설명이
> 안 된다. **선이 정말 안 움직인다.**

#### ★향후 `~INT` 를 쓸 때의 함정 2가지 (pad1 수리 후에도 유효)

1. **빠른 탭은 통째로 놓칠 수 있다.** 떼는 순간 INT 가 자가 해제되므로, ISR/읽기가
   늦으면 포트가 이미 원래 값으로 돌아가 있어 **읽어도 아무 변화가 없다.**
2. **폴링과 INT 를 섞으면 이벤트가 손실된다.**
   *"Interrupts that occur during the ACK clock pulse **can be lost** (or be very short),
   due to the resetting of the interrupt during this pulse"*
   LP 코어가 2 ms 마다 I²C 트랜잭션을 돌리므로 그 ACK 구간에 떨어지는 엣지는 조용히
   사라진다. ②(인터럽트 기반)로 전환하려면 **폴링을 완전히 끄는 설계**라야 한다.

> 같은 이유로 **`intdiag` 는 LP 코어 폴링을 반드시 멈춰야 한다**(2026-08-15 수정 완료).
> LP 가 2 ms 마다 PCF 를 읽으면 INT 가 계속 해제되어 관찰 구간이 통째로 HIGH 로 보인다.
> ※최초 측정(2026-08-13 13:46, `1bbcbc5`)은 LP 코어 도입(18:54, `f45ac86`)보다 5시간
> 앞서서 이 문제가 없었다 — 그때 판정 자체는 유효하다. 하지만 **재검증 시에는 이 수정이
> 없으면 무조건 "여전히 죽음" 으로 나온다.**

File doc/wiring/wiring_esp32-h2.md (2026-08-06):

# 배선도 — ESP32-H2 SuperMini (검증)

> **보드 핀맵 단일 진실원천: [`main/boards/esp32-h2.h`](../../main/boards/esp32-h2.h)**
> 핀 출처: `doc/esp32/SuperMini/` (핀맵 `esp32-h2-supermini0.jpg`·`esp32_h2_superMini1.jpg`
> + 회로도 `esp32-h2-superMini2.png`). 실물 동작 검증 완료.

- **SoC / IDF target**: ESP32-H2 (RISC-V, 802.15.4 + BLE, **WiFi 없음**) / `esp32h2`
- **트랜스포트**: Thread 만 가능 → **Matter over Thread** (Thread Border Router 필요)
- **OLED**: 외부 모듈 (기본 72×40 가정 — 실제 패널에 맞춰 `BOARD_OLED_*` 조정).
  렌더러는 **해상도로 자동 선택** — 128×64 모듈을 달면 풀스크린 네이티브 렌더러가
  자동 적용된다(`esp32-h2.h` 를 128×64/OFFSET 0/FIXUP 0 으로, `sdkconfig` `CONFIG_OFFSETX=0`)
- **첫 빌드 전 1회**: `./build.ps1 -Board esp32-h2 -Action set-target`
- **빌드**: `./build.ps1 -Board esp32-h2 -Action build -Rotate 180` — 현 시제품 기판은 OLED 가 **180° 장착**이라 `-Rotate 180` 필수(flash·ota-image 도 동일)

## 핀맵 이미지 (SuperMini)

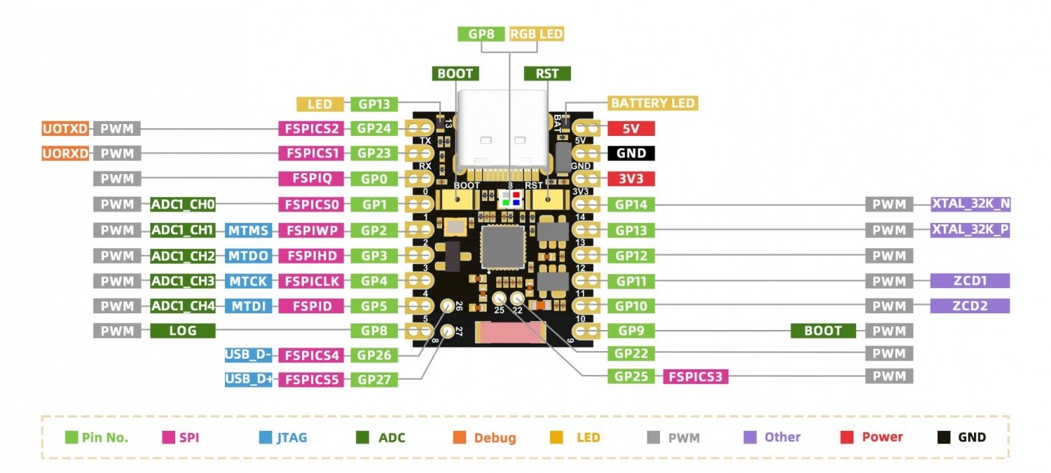
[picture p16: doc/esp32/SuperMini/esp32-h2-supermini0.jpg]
ESP32-H2 SuperMini 핀맵


> 회로도: [`esp32-h2-superMini2.png`](<../esp32/SuperMini/esp32-h2-superMini2.png>).
> 핀 번호 최종 기준은 아래 표(=`boards/esp32-h2.h`). **GP6/GP7 미노출**, GP8(LED)·
> GP9(BOOT)·GP26/27(USB) 회피.

## CC1101 모듈 (E07-M1101D-SMA) 핀맵

E07-M1101D-SMA 핀맵

> ※ **제작 보드는 E07-400MM10S 모듈** 사용 — 같은 CC1101 칩이라 핀맵은 동일하나, 크리스털 오차가
>   달라 register **447.70** → on-air 447.673 MHz(실제 블라인드 인식 확인). 테스트용 E07-M1101D-SMA 는
>   447.72 → 447.675. 주파수 상세는 README "RF / Somfy RTS 447" 섹션 참고.

## ★ I2C 공유 (이 보드의 핵심 차이)

ESP32-H2 에는 **LP_I2C 가 없고** SuperMini 의 가용 핀도 빠듯하다. 그래서
**OLED 와 PCF8574 를 하드웨어 I2C 한 버스에 공유**한다(SDA/SCL 동일 핀, 주소만
다름: OLED `0x3C` / PCF8574 `0x20`).

- 보드 파일에서 `BOARD_I2C_SHARED = 1`, 그리고 `BOARD_PIN_OLED_SDA == BOARD_PIN_PCF_SDA`,
  `BOARD_PIN_OLED_SCL == BOARD_PIN_PCF_SCL` (board_select.h 가 컴파일타임에 검증).
- 펌웨어: 공유 시 PCF8574 는 비트뱅이 아니라 **OLED 가 만든 i2c_master 버스에
  device 로 붙어** 폴링한다(`button_handler.c` 의 `BOARD_I2C_SHARED` 분기 →
  `i2c_master_bus_add_device` + `i2c_master_receive`). 버스 접근은 새 I2C 드라이버가
  내부적으로 직렬화하므로 OLED 갱신과 PCF 폴링이 안전하게 공존한다.
- **GNPE 는 공유 안 함**(OLED=HW I2C + PCF8574=비트뱅, 서로 다른 핀, `BOARD_I2C_SHARED=0`).
  **XIAO 는 H2 와 동일하게 공유**(`BOARD_I2C_SHARED=1`, OLED 버스에 PCF device) — XIAO
  실기에서 이 공유 경로가 처음 검증됐고, 그 과정에서 읽기 타임아웃 버그(5ms→50ms)도 수정됨.

> 공유 버스이므로 **외부 4.7 kΩ pull-up 은 SDA/SCL 각 1개씩만** 필요(OLED·PCF 공통).

## 핀 매핑 (SuperMini 실측 기반)

| 기능 | 신호 | GPIO | 비고 |
|---|---|---|---|
| CC1101 | SCK  | **GP4**  | FSPICLK (IO-MUX 네이티브) |
| CC1101 | MISO | **GP0**  | FSPIQ |
| CC1101 | MOSI | **GP5**  | FSPID |
| CC1101 | CS | **GP1**  | (FSPICS0) active-LOW |
| CC1101 | GD0  | **GP10** | RMT 비동기 TX 데이터 |
| **I2C 공유** | SDA | **GP13** | OLED+PCF8574 공통, 4.7 kΩ pull-up (구 GP12) |
| **I2C 공유** | SCL | **GP14** | OLED+PCF8574 공통, 4.7 kΩ pull-up (구 GP22) |
| PCF8574 | ~INT | **GP11** | active-LOW wake, 10 kΩ pull-up |
| 센서 | CHG_STAT | **GP12** | **USB 감지** — VBUS 분압 active-HIGH (충전 섹션) |
| 센서 | BAT ADC | **GP3** | 배터리 전압 분압 ADC → 실측 % (충전 섹션) |
| 센서 | VIBE | **GP2** | VS1 진동 스위치 (비-strapping 가용핀, 구 GP25) |

## PCF8574 (I2C addr 0x20, bit-bang)

`A0/A1/A2 → GND` (주소 0x20). 8개 P-핀은 회로 고정:

| P-핀 | 연결 | 기능 |
|---|---|---|
| P0 | ROT_A | 로터리 CW/CCW |
| P1 | ROT_B | 로터리 CW/CCW |
| P2 | ROT_BTN | 클릭=STOP/MY (주파수 편집은 설정 메뉴 `Freq Edit` — v3.5 이후) |
| P3 | SW6 SETUP | 짧게=설정 메뉴, 2초=메뉴 항목 저장/실행 |
| P4 | SW1 UP | 블라인드 ↑ |
| P5 | SW2 DOWN | 블라인드 ↓ |
| P6 | SW3 SELECT | 블라인드 선택 순환 |
| P7 | SW4 PROG | Somfy PROG (2초 롱프레스=모터 등록) |

## ⚠️ SuperMini 미노출/금지 핀

| GPIO | 사유 |
|---|---|
| **GP6 / GP7** | SuperMini 에 **미노출** |
| GP8 | RGB LED / LOG (+ strapping) — 사용 금지 |
| GP9 | BOOT strapping |
| GP26 / GP27 | USB D-/D+ |
| GPIO15~21 | in-package SPI flash |

**노출 핀**: GP0-5 · GP10-14 · GP22-25. **사용 중**: CC1101(GP0/1/4/5/10) · I2C(GP13/14) ·
~INT(GP11) · CHG_STAT(GP12) · BAT ADC(GP3) · VIBE(GP2). → **현재 여유: GP22·GP23·GP24·GP25.**
(GP13/GP14 는 32.768kHz xtal 겸용 — SuperMini 는 외부 32K 미실장이라 일반 GPIO 로 사용
가능하며 **현재 I2C(SDA=GP13/SCL=GP14)에 배정**. 외부 32K 크리스털을 달 거면 I2C 를 다른 핀으로.)

## 🔋 충전 / 배터리

**온보드 충전회로** (스키매틱 [`esp32-h2-superMini2.png`](<../esp32/SuperMini/esp32-h2-superMini2.png>)):
- 충전 IC **TP4054**(SOT23-5, 단셀 Li-ion), **R_PROG=10 kΩ → ~100 mA**.
- 파워패스 BAT→Schottky(PD1)→VCC, **LDO ME6217C33**(3.3V). BAT 패드에 단셀 LiPo 직결.
- 충전 status(CHRG)는 **녹색 LED 전용**이라 GPIO 로 안 빠짐(XIAO NCHG 와 동일).

**충전 감지 — A+B** (펌웨어 구현됨 · `BOARD_CHG_STAT_ACTIVE_HIGH=1` · `BOARD_HAS_BAT_ADC=1`).
**배터리 쓸 때만** 분압 2개를 납땜한다:

```
A. USB 감지 :  VBUS(5V) ──100k──◉──150k──GND      ◉ = CHG_STAT(GP12), active-HIGH
B. 배터리   :  BAT ──────100k──◉──100k──GND       ◉ = GP3 (ADC) → OCV-SoC → 실측 %
```

- **충전중** = A(USB)=HIGH AND Vbat < ~4.15V / **만충** = A AND Vbat ≈ 4.2V.
- 배터리 미사용 시 **생략 가능**(펌웨어 정상 — 충전 애니메이션만 비활성). 폴백 추정시간은
  `BOARD_BATT_MAH` · `BOARD_CHG_MA=100` 에서 파생.
- ⚠ B 분압 기생소모 ~21 µA(100k/100k). 절전 중요하면 **1M/1M + ADC 노드 100 nF**.
- 단셀은 **PCM(보호회로) 내장 셀** 권장 — TP4054 는 충전만, 과방전 보호는 셀 PCM.

> ⚠️ **현 시제품 기판은 위 A·B 분압이 핀에서 뒤바뀌어 있다**(BAT_ADC핀 **GP3 ← VBUS** 100k/150k,
>   CHG_STAT핀 **GP12 ← BAT** 100k/100k). GP12 는 ADC·아날로그 comparator 불가핀(H2 ADC=GP1~5,
>   ana_cmpr SRC=GP11)이라 **배터리 잔량 % 측정이 물리적으로 불가** → `boards/esp32-h2.h` 의
>   **`BOARD_BAT_SWAPPED=1`** 로 화면 우상단에 **`USB`/`BAT`/`LOW` 상태**를 표시한다(GP3 의 VBUS 를
>   ADC 로 읽어 USB 감지 + GP12 내부풀업 1임계≈3V 로 저전압 판별). 위 **정상 배선(BAT→GP3, VBUS→GP12)
>   으로 기판을 고치면 `BOARD_BAT_SWAPPED=0`**(기본값) → 기존 충전률 % 표시로 자동 복귀(두 경로 코드 보존).

## 비고

- CC1101 SPI 는 H2 의 **GPSPI2(FSPI) IO-MUX 네이티브 핀**(CLK=GP4/D=GP5/Q=GP0)에 배치.
- CC1101 은 **3.3V 전용** — 5V 금지.
- Thread Border Router 필요 (SmartThings Hub v3+, Apple TV 4K 등).

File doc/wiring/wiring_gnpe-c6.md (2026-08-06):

# 배선도 — GNPE ESP32-C6-0.42

> **보드 핀맵 단일 진실원천: [`main/boards/gnpe-c6.h`](../../main/boards/gnpe-c6.h)**
> 이 표는 그 헤더에서 파생했다. 헤더가 바뀌면 이 문서도 갱신할 것.
> 상세 다이어그램(전원 정책·절전·UX·PCB 변형 등) 은 [`wiring_gnpe-c6.html`](wiring_gnpe-c6.html).

- **브랜드/제품**: GNPE "ESP32-C6-0.42" (현 검증 보드 · 문서 핀맵 기준)
- **SoC / IDF target**: ESP32-C6 (RISC-V, 802.15.4 + BLE) / `esp32c6`
- **Matter Product ID**: `0x8000` (OTA 보드 매칭, `sdkconfig.defaults.c6_thread`)
- **OLED**: SSD1315 **72×40**, 거꾸로 장착(SW 180° 회전), 컬럼 오프셋 28 —
  **보드 내장 배선(IO0/IO1, 변경 불가)**. 규격은 `boards/gnpe-c6.h` 의 `BOARD_OLED_*`
  (+ `sdkconfig` `CONFIG_OFFSETX=28`).
  - 🔀 **렌더러는 해상도로 자동 선택**(보드에 고정 아님). 72×40 이므로 논리 캔버스
    렌더러가 적용된다. **다른 규격 OLED 를 연결**하려면(I2C 핀이 노출된 변형/외부 모듈)
    `gnpe-c6.h` 의 `BOARD_OLED_*` 만 그 패널 규격으로 바꾸면 된다 — 예: 128×64 로 바꾸면
    풀스크린 네이티브 렌더러(고딕+7세그)가 자동 적용된다(`OFFSET 0`, `FIXUP 0`,
    `sdkconfig` `CONFIG_OFFSETX=0` 동반). 코드 수정 불필요.
- **빌드**: `./build.ps1 -Board gnpe-c6 -Action build` (기본 보드)

## 핀맵 이미지

### GNPE ESP32-C6-0.42 핀맵

GNPE ESP32-C6-0.42 핀맵

### CC1101 모듈 (E07-M1101D-SMA) 핀맵

E07-M1101D-SMA 핀맵

> ⚠️ 핀 번호의 최종 기준은 아래 표(=`boards/gnpe-c6.h`). 이미지는 보드/모듈
> 물리 위치 파악용 참고.

## 핀 매핑 (요약)

| 기능 | 신호 | ESP32-C6 GPIO | 비고 |
|---|---|---|---|
| CC1101 | SCK  | **IO6**  | FSPICLK (IO-MUX) |
| CC1101 | MISO | **IO2**  | FSPIQ (IO-MUX) |
| CC1101 | MOSI | **IO7**  | FSPID (IO-MUX) |
| CC1101 | CS | **IO4**  | (FSPICS0) active-LOW |
| CC1101 | GD0  | **IO8**  | RMT 비동기 TX 데이터 |
| OLED | SDA  | **IO1**  | 실크 `SDA-1`, 내장 배선 |
| OLED | SCL  | **IO0**  | 실크 `SCL-0`, 내장 배선 |
| PCF8574 | SDA | **IO19** | bit-bang I2C, 외부 4.7 kΩ pull-up |
| PCF8574 | SCL | **IO18** | bit-bang I2C, 외부 4.7 kΩ pull-up |
| PCF8574 | ~INT | **IO17** | active-LOW wake, 외부 10 kΩ pull-up |
| 센서 | CHG_STAT | **IO3** | MCP73831 STAT (active-LOW), sleep wake |
| 센서 | VIBE | **IO16** | VS1 진동 스위치, sleep wake |

> ℹ️ CC1101 SPI 핀 단일 진실원천은 `gnpe-c6.h`(위 표: SCK=IO6 / MOSI=IO7 / MISO=IO2 / CS=IO4).
> `wiring_gnpe-c6.html` 다이어그램도 현행 값으로 갱신됨(옛 v2.0 표기는 변경이력 섹션에만 보존).

## CC1101 ↔ ESP32-C6

| CC1101 핀 | 신호 | GPIO | 비고 |
|---|---|---|---|
| Pin1 GND  | GND  | GND  | 공통 GND |
| Pin2 VCC  | +3.3V | 3V3 | ⚠ **3.3V 전용** — 5V 연결 시 파손 |
| Pin3 GDO0 | TX Data | IO8 | RMT 비동기 TX |
| Pin4 CSN  | SPI CS | IO4 | active-LOW |
| Pin5 SCK  | SPI Clock | IO6 | |
| Pin6 MOSI | SPI Data OUT | IO7 | |
| Pin7 MISO | SPI Data IN | IO2 | |
| Pin8 GDO2 | NC | — | 연결 불필요 |

## PCF8574 (I2C addr 0x20, bit-bang)

`A0/A1/A2 → GND` (주소 0x20). 8개 P-핀은 회로 고정:

| P-핀 | 연결 | 기능 |
|---|---|---|
| P0 | ROT_A | 로터리 CW/CCW |
| P1 | ROT_B | 로터리 CW/CCW |
| P2 | ROT_BTN | 클릭=STOP/MY (주파수 편집은 설정 메뉴 `Freq Edit` — v3.5 이후) |
| P3 | SW6 SETUP | 짧게=설정 메뉴, 2초=메뉴 항목 저장/실행 |
| P4 | SW1 UP | 블라인드 ↑ |
| P5 | SW2 DOWN | 블라인드 ↓ |
| P6 | SW3 SELECT | 블라인드 선택 순환 |
| P7 | SW4 PROG | Somfy PROG (2초 롱프레스=모터 등록) |

## Light-sleep Wake 소스

| GPIO | 소스 | 트리거 |
|---|---|---|
| IO17 | PCF8574 ~INT | P0~P7 중 변화 (모든 버튼/로터리) |
| IO16 | VS1 진동 | 접점 닫힘 (active-LOW) |
| IO3  | MCP73831 STAT | 충전 시작 (open-drain LOW) |

## 조립 주의

- CC1101 은 **3.3V 전용** — 5V 금지.
- 외부 풀업: PCF8574 SDA/SCL 각 **4.7 kΩ**, ~INT **10 kΩ** → +3V3.
- OLED(HP I2C0, IO0/IO1, 내장) ↔ PCF8574(bit-bang, IO18/IO19) — 핀 충돌 없음.
- 각 VCC 핀 근처 **100 nF 디커플링** 권장.

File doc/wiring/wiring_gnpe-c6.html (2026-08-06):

# 🔌 Somfy RTS Blind Controller — 배선도 보드: GNPE ESP32-C6-0.42

GNPE ESP32-C6-0.42 + CC1101 + PCF8574 + EC11 | Matter over Thread (SED) + 설정 메뉴 + UX 개선

📌 보드별 배선 문서

이 문서는 GNPE "ESP32-C6-0.42" 보드 전용 상세 배선도다(내장 OLED·내장 배선 IO0/IO1 등 이 보드 고정 사항 포함). 다른 보드는 핀 배열이 다르므로 별도 문서를 본다:

- GNPE ESP32-C6-0.42 — 본 문서 (검증 보드 · 기준)
- Seeed XIAO ESP32-C6 — wiring_xiao-c6.md
- ESP32-H2 (Thread, 검증) —wiring_esp32-h2.md

⚠ 핀맵의 단일 진실원천은 main/boards/<board>.h 다. 아래 일부 버전 이력 섹션은 과거 표기(예: 구 PCB 변형 _v/_h, 4-항목 설정 메뉴)를 보존하므로 현행과 다를 수 있다 — 현행 사실은 main/boards/gnpe-c6.h · 루트 README.md 우선.

✨ v3.6 — UX 개선 + 시간 영속화 + 핵심 버그 수정 (2026-05-15)

- 버튼 모션 정리: 텍스트 라벨 (UP/DN/STOP/B1/ALL) 제거 — 깔끔한 풀스크린 모션
- 틸트 모션 개선: 3장 블라인드 슬랫 회전 (좁고 과감, half_w=18px, tilt 0→8px, 1.2s 사이클)
- SELECT 중단 + 블라인드 순환: 모션 진행 중 SELECT 누르면 즉시 중단하고 다음 블라인드로 순환
- 설정 메뉴 정리: 숫자 prefix 제거, Cancel 첫 항목 (메뉴: Cancel / Freq Edit / Matter Pair / Thread Rst)
- SmartThings 명령 wake + 모션: sleep/screensaver 중 명령 수신 시 즉시 wake + 해당 모션 표시
- 시간 영속화: 5분마다 epoch 를 NVS 저장 → 리셋 후 시계 복원 (BUILD/NVS 출처 로그)
- SNTP 1시간 주기: esp_sntp_set_sync_interval(3600000) + 동기화 callback 으로 NVS 즉시 저장
- 진동 wake 활성화: VIBE 감지 시 자동 활성 모드 복귀 (`_exit_screensaver/sleep`)
- ★ 핵심 버그 수정: matter_blinds.cpp 의 attribute callback fall-through → 연속 버튼 입력 시 갑작스러운 STOP 모션 / 가짜 STOP RF 송신 제거 (handled flag 추가)
- 크기: 0x1CEB20 bytes (53% 여유)

⚡ v3.3 — Sleepy End Device + 자동 light sleep (2026-05-15)

- Matter ICD (Intermittently Connected Device) Server 활성화 → esp-matter 가 Thread device type 자동 SED 설정
- Thread SED — slow poll 5초로 부모 노드에서 큐된 Matter 명령 수신. 절전 모드에서도 Matter 명령 수신 가능
- ESP-IDF PM (Power Management) auto light sleep — tickless idle + CPU DFS (80/160MHz)
- Sleep 진입 단순화: esp_light_sleep_start() 호출 제거 → OLED off + PM 이 자동 sleep 진입
- Matter 명령 응답 지연 최대 5초 (ICD slow poll period; 필요시 조정 가능)

📋 v3.2 — 전원 상태별 idle 정책 (2026-05-14)

- USB 연결: 3분 무입력 → 화면 보호기 (OLED off, CPU/Matter 정상)
- 배터리 전용: 1분 무입력 → 절전 모드 (OLED off + PM auto-sleep, SED 가 Matter 수신 유지)
- 버튼 / SmartThings 명령 / 진동 / 충전 시작 → 두 모드 모두 즉시 해제

🔧 v3.1 — 설정 메뉴 (2026-05-14)

- SW6 SETUP 짧게 → 4-item 메뉴: 1.주파수 편집 2.Matter 페어링 3.Thread 리셋 4.취소
- UP/DOWN/tilt 로 커서 이동, SW6 짧게 = 선택, SW6 2초+ = 저장/실행, STOP = 취소
- PROG 버튼의 Matter 페어링/Thread 리셋 기능 제거 (메뉴로 이관)

🧵 v3.0 — WiFi → Thread 전환 (2026-05-13)

- SmartThings 연결을 WiFi → Thread (802.15.4) 로 전환 — ESP32-C6 내장 라디오
- WiFi 코드 전면 제거 (SoftAP / HTTP 서버 / 자격증명 저장 미사용)
- OpenThread + esp-matter Thread 트랜스포트, BLE 커미셔닝 유지
- Thread Border Router 필요 (SmartThings Hub v3+/HomePod mini/Nest Hub 등)

🔄 v2.0 핀 재배치 (2026-05-13) — 유지

- ESP32 GPIO 전면 재배치 — SPI/I2C swap, PCF8574_INT → IO17
- 모든 4 + 1 버튼 (SW1~4, SW6) PCF8574 이관 — ESP32 direct GPIO 사용 안 함
- PCF8574 I2C → IO18/IO19 (software bit-bang)
- PCF8574 ~INT (Pin13) → IO17 — 모든 P 변화 시 light sleep wake
- PCB 두께 1.0mm, ANT_447M 트랙폭 1.712mm (Er=4.5 microstrip 50Ω)

## 📊 전체 배선 다이어그램

wiring_diagram.svg (SVG 미지원 브라우저)

📐 원본 파일: wiring_diagram.svg — Inkscape/Illustrator에서 편집 가능 | ⚠ SVG 는 v1.x 상태일 수 있음 — 본 HTML 표가 truth.

## 📋 ESP32-C6-0.42 핀 매핑 (v2.0) 전면 재배치

GPIO | 현행 신호 | v1.x 신호 (구) | 비고
IO0 | OLED SCL | OLED SCL | HP I2C0, 보드 내장 (변경 불가)
IO1 | OLED SDA | OLED SDA | HP I2C0, 보드 내장 (변경 불가)
IO2 | CC1101 MISO | BTN_PROG | FSPIQ (네이티브)
IO3 | CHG_STAT | BTN_UP | MCP73831 STAT, sleep wake source
IO4 | CC1101 CSN | SPI_SCK | SPI CS (Active-LOW)
IO5 | — (NC) | SPI_MISO | 현행 미사용 (MISO→IO2)
IO6 | CC1101 SCK | LP_I2C_SDA | FSPICLK (네이티브)
IO7 | CC1101 MOSI | LP_I2C_SCL | FSPID (네이티브)
IO8 | CC1101 GD0 | CC1101 GD0 | RMT 비동기 TX (유지)
IO16 | VIBRATION | BTN_DOWN | VS1 진동 센서, sleep wake source
IO17 | PCF8574 ~INT | BTN_SELECT | 모든 P 변화 wake, 외부 10kΩ pull-up 필수
IO18 | PCF8574 SCL (bit-bang) | CC1101 MOSI | software I2C 50kHz, 4.7kΩ pull-up
IO19 | PCF8574 SDA (bit-bang) | CC1101 CSN | software I2C 50kHz, 4.7kΩ pull-up

## 📋 CC1101 ↔ ESP32 (현행)

CC1101 핀 | 신호 | ESP32-C6 GPIO | 와이어 색 | 비고
Pin1 GND | GND | GND | 검정 | 공통 GND
Pin2 VCC | +3.3V | 3V3 | 빨강 | ⚠ 반드시 3.3V — 5V 연결 시 파손
Pin3 GD00 | TX Data | IO8 | 주황 | RMT 비동기 TX (유지)
Pin4 CSN | SPI CS | IO4 | 파랑 | v2.0 swap (구 IO19)
Pin5 SCK | SPI Clock | IO6 | 파랑 | FSPICLK 네이티브
Pin6 MOSI | SPI Data OUT | IO7 | 파랑 | FSPID 네이티브
Pin7 MISO | SPI Data IN | IO2 | 파랑 | FSPIQ 네이티브
Pin8 GD02 | NC | - | - | 연결 불필요

## 📋 버튼 / 센서 (v2.0 — 모두 PCF8574 또는 GPIO 직결)

★ v2.0: 모든 버튼은 PCF8574 로 이관됨 (ESP32 GPIO direct 사용 안 함). 센서 (VS1 진동 / MCP73831 충전) 은 GPIO 직결 + sleep wake source.

컴포넌트 | 연결 | 기능 | 롱프레스 (2초/5초)
SW1 UP | PCF8574 P4 (Pin9) | 블라인드 올리기 ↑ | -
SW2 DOWN | PCF8574 P5 (Pin10) | 블라인드 내리기 ↓ | -
SW3 SELECT | PCF8574 P6 (Pin11) | 블라인드 선택 순환 | -
SW4 PROG | PCF8574 P7 (Pin12) | Somfy PROG 커맨드 | 2초 = Somfy 리모컨 등록(PROG)
SW6 SETUP | PCF8574 P3 (Pin7) | 짧게 = 설정 메뉴 / 항목 활성화 / 편집 저장 | 2초 = 편집 저장 · Thread 실행
로터리 회전 | PCF8574 P0/P1 | CW/CCW (틸트 ± / 주파수 ±0.01MHz) | -
로터리 클릭 | PCF8574 P2 (Pin6) | 정지 / MY 커맨드 | 설정 화면 = 취소·복귀 (구 "2초=주파수편집"은 v3.5 제거)
SW5 STOP (_v / _v2만) | 로터리와 wired-OR | 보조 정지 (로터리 클릭 동등) | -
VS1 VIBRATION (_v2 / _h2만) | IO16 (GPIO 직결) | 흔들기 감지 → light sleep wake | -
MCP73831 STAT (배터리 변형) | IO3 (GPIO 직결) | 충전 시작 → light sleep wake | -

## 📋 PCF8574 (v2.0) — bit-bang I2C 0x20 IO18/IO19

★ v2.0: HP_I2C0 는 OLED 전용, LP_I2C0 는 LP_GPIO6/7 핀 고정. PCF8574 는 IO18/19 에서 소프트웨어 비트뱅 I2C (50kHz, ~10ms 폴링). 외부 4.7kΩ pull-up 필수.

PCF8574 핀 | v2.0 연결 | v1.x 연결 (구) | 비고
Pin1 A0 | GND | GND | I2C 주소 bit0 = 0
Pin2 A1 | GND | GND | I2C 주소 bit1 = 0
Pin3 A2 | GND | GND | addr 0x20
Pin4 P0 | EC11 A상 (ROT_A) | ROT_A | 로터리 CW/CCW
Pin5 P1 | EC11 B상 (ROT_B) | ROT_B | 로터리 CW/CCW
Pin6 P2 | EC11 BTN (ROT_BTN) | ROT_BTN | 클릭 = STOP/MY, 2초 = 주파수 편집
Pin7 P3 | SW6 BTN_SETUP | MCP73831 STAT | v2.0 변경 (STAT → IO3 직결로 이전)
Pin8 GND | GND | GND
Pin9 P4 | SW1 BTN_UP | VS1 진동 | v2.0 변경 (VS1 → IO16 직결로 이전)
Pin10 P5 | SW2 BTN_DOWN | SW6 SETUP | v2.0 변경 (SETUP → P3 이전)
Pin11 P6 | SW3 BTN_SELECT | NC | v2.0 신규 (ESP32 IO17 → P6 이전)
Pin12 P7 | SW4 BTN_PROG | NC | v2.0 신규 (ESP32 IO2 → P7 이전)
Pin13 ~INT | → IO17 (ESP32, wake source) | NC | ★ v2.0 신규 — 모든 P 변화 시 LOW, 외부 10kΩ pull-up 필수
Pin14 SCL | IO18 (bit-bang) | IO7 (LP_GPIO7) | v2.0: software I2C 50kHz
Pin15 SDA | IO19 (bit-bang) | IO6 (LP_GPIO6) | v2.0: software I2C 50kHz
Pin16 VCC | 3V3 | 3V3 | 외부 4.7kΩ pull-up 필수 (SDA/SCL 각 1, +3.3V)

## 📋 OLED I2C (HP I2C0, ESP32-C6-0.42 보드 내장 IO0/IO1)

신호 | GPIO | 실크 | I2C 주소 | 해상도 | 비고
SDA | IO1 | SDA-1 | 0x3C | 72 × 40 px | HP I2C0 — 보드 하드와이어 (변경 불가)
SCL | IO0 | SCL-0 | | | HP I2C0 — 보드 하드와이어 (변경 불가)

SSD1315(72×40)는 SSD1306 컨트롤러 기반이지만 패널이 SEG28..SEG99 구간에 매핑되어 CONFIG_OFFSETX=28 + multiplex(0xA8 0x27) / COM pin map(0xDA 0x12) / IREF(0xAD 0x30) 보정 명령 필요.

✓ HP I2C0(OLED, IO0/1) ↔ PCF8574 bit-bang(IO18/19) — 핀 충돌 없음, 독립 동작

## 📋 Light Sleep Wake Sources (v2.0)

v2.0: 3개 GPIO 모두 LOW level 로 wake 가능. timer wake 불필요.

Wake 핀 | 소스 | 트리거 | 용도
IO17 | PCF8574 ~INT (Pin13) | P0-P7 중 어느 비트라도 변화 | 모든 버튼/로터리 wake
IO16 | VS1 진동 센서 | 접점 닫힘 (active-LOW) | 흔들기 wake
IO3 | MCP73831 STAT | 충전 시작 (open-drain LOW) | USB 연결 즉시 화면 ON

✓ Light sleep 전류 ~750µA → 600mAh 33일 standby

## 📋 전원 공급

전원 | 전압 | 공급처 | 소비 디바이스
USB-C (USB 5V) | 5V | ESP32-C6-0.42 USB-C 포트 | 보드 내부 3.3V 레귤레이터
3.3V 레귤레이터 | 3.3V | ESP32-C6-0.42 3V3 핀 | CC1101, PCF8574, EC11, 버튼, VS1, 풀업
BAT+ (배터리 변형) | 3.0~4.2V | 851640 LiPo 600mAh | D1(SS14) → +5V 레일 (USB 분리 시)

✓ 총 소비전류: ESP32-C6 ~150mA + CC1101 TX ~30mA + PCF8574 ~1mA = ~180mA (USB 500mA 한계 36%)

✓ SPICE DC OP 검증: V_USB=5V, I_USB=65mA, +3V3=3.3V, P_dissipated=127mW (LDO heat)

✓ SPICE Transient (300mA TX burst): +3V3 droop=36mV (정격 ±165mV 의 22%)

## ⚡ 전원 정책 + 절전 (v3.3)

전원 상태 | 활성 | idle 대응 | idle 후 모드
USB 연결 (충전 중 또는 최근 1분) | OLED on, CPU full, Matter 명령 즉시 수신 | 3분 무입력 | 화면 보호기 — OLED off, CPU/Thread 정상, Matter 즉시 수신
배터리 전용 | OLED on, CPU full (PM 이 idle 시 자동 light sleep) | 1분 무입력 | 절전 모드 — OLED off + PM auto-light-sleep + Thread SED 5s poll

SED (Sleepy End Device) 절전 메커니즘: Thread MTD 가 부모 노드에 5초마다 data poll 송신. 부모 노드는 Matter 명령을 큐에 저장 후 다음 poll 시 전달. CPU 는 5초 중 99% 이상 light sleep 상태. 수신 시 Thread interrupt 가 CPU wake → Matter callback → 블라인드 동작.

### Wake 트리거 (모든 모드)

Wake 원인 | 핀 | 동작
버튼 / 로터리 | IO17 (PCF8574 ~INT) | _btn_event_cb → activity mark + _exit_sleep
진동 (VS1) | IO16 | main loop poll + GPIO LOW level wake
USB 연결 (충전 시작) | IO3 | main loop poll + GPIO LOW level wake
SmartThings 명령 | 802.15.4 RF | Thread SED slow poll (5s) → Matter callback → activity mark + _exit_sleep

### PM (Power Management) 설정

CONFIG_PM_ENABLE=y                            # 활성화
CONFIG_PM_DFS_INIT_AUTO=y                     # DFS 자동: 80MHz idle / 160MHz active
CONFIG_PM_POWER_DOWN_CPU_IN_LIGHT_SLEEP=y     # CPU power-down OK
# CONFIG_PM_POWER_DOWN_PERIPHERAL_IN_LIGHT_SLEEP NOT SET  # 주변기기 유지 (안전)
CONFIG_FREERTOS_USE_TICKLESS_IDLE=y           # tickless idle → 자동 light sleep
CONFIG_FREERTOS_IDLE_TIME_BEFORE_SLEEP=3      # 3 tick 후 sleep

# Matter ICD (SED 자동 설정 트리거)
CONFIG_ENABLE_ICD_SERVER=y
CONFIG_ICD_SLOW_POLL_INTERVAL_MS=5000         # 평상시 5s poll
CONFIG_ICD_FAST_POLL_INTERVAL_MS=200          # 활성 시 200ms
CONFIG_ICD_ACTIVE_MODE_INTERVAL_MS=300        # 명령 후 300ms 활성 유지

### 코드 초기화 순서

app_main() {
  init_rtc_from_build_time();
  blind_manager_init();
  cc1101_init();              // SPI 초기화 (full-speed 필요)
  somfy_rts_init();
  oled_ui_init();
  oled_ui_start_task();
  btn_handler_init();         // bit-bang I2C 초기화
  btn_handler_start_task();
  thread_prov_init();
  matter_blinds_init();
  matter_blinds_start();      // OpenThread + Matter 시작
                              //   → ICD_SERVER=y 이면 SED 모드 자동 설정
  /* RF worker + time + hold_repeat 태스크 */

  gpio_wakeup_enable(...);    // GPIO wake source 등록
  esp_sleep_enable_gpio_wakeup();

  esp_pm_configure(&pm_cfg);  // ★ 모든 init 완료 후! 그래야 init 도중
                              //   tickless idle 데드락 방지
  while (1) { main_loop }
}

## 🎨 UX / 화면 모션 (v3.6)

### 버튼 모션 (OLED_STATE_ACTION)

모션 | 트리거 | 시각 효과 (72×40 OLED, 2.5s)
UP | SW1 / SmartThings UP / 로터리 CW (없음) | 큰 화살표 위 방향 슬라이드
DOWN | SW2 / SmartThings DOWN | 큰 화살표 아래 방향 슬라이드
STOP (MY) | 로터리 클릭 / SmartThings MY | 정사각형 + 펄스
PROG | SW4 / SmartThings PROG | 동심원 펄싱
TILT UP | 로터리 CW | 3장 블라인드 슬랫 우측 끝이 위로 (8px tilt, 1.2s)
TILT DN | 로터리 CCW | 3장 슬랫 우측 끝이 아래로

★ v3.6: 좌상단 텍스트 라벨 (UP/DN/STOP) 및 우상단 블라인드 번호 (B1/ALL) 제거 — 깔끔한 풀스크린 모션.

### 모션 중 SELECT 버튼

OLED 모션 진행 중 SW3 SELECT 누르면 → 즉시 모션 중단 + 다음 블라인드로 순환. 이전 v3.4: 모션 중단만 (순환 안 함). 현재 v3.6: 중단 + 순환 (한 번에 둘 다).

### SmartThings 명령 wake

Sleep / 화면보호기 중 SmartThings 명령 수신 시:

1. Thread SED slow poll (5s) 으로 명령 도달
2. _exit_sleep() / _exit_screensaver() → OLED 패널 ON, 활성 모드 복귀
3. oled_ui_notify_action_start() → 해당 모션 (UP/DN/STOP/PROG) 표시 2.5초
4. RF 큐로 송신 (등록된 endpoint 만)

## 📋 설정 메뉴 (v3.5+ — 정리됨)

SW6 SETUP 짧게 → 메뉴 진입. 4 항목, OLED 가독성 개선 (숫자 prefix 제거).

순서 | 항목 | 동작
1 | Cancel | SETUP 짧게 → 즉시 메인 복귀 (실수 진입 시 빠른 탈출)
2 | Freq Edit | FREQ_EDIT 화면 진입 → 로터리/UP/DN 으로 freq ±0.01 MHz
3 | Matter Pair | BLE 광고 시작 + PIN/QR 표시 (코드는 eFuse 기반 기기 고유)
4 | Thread Rst | 확인 화면 → SETUP 2초+ 로 실행 (Thread dataset erase)

### 메뉴 / 하위 화면 버튼 매트릭스

입력 | SETUP_MENU | FREQ_EDIT | MATTER_PAIR / THREAD_RST
SW6 SETUP 짧게 | 선택 항목 진입 | 저장 후 복귀 (v3.9) | Matter=READY 확정 / Thread=메뉴
SW6 SETUP ≥2s | (무시) | 저장 + 복귀 | 실행 (Thread Rst) / 무시
로터리 CW/CCW | 커서 ↑/↓ | freq ±0.01 | (무시)
UP / DOWN 버튼 | 커서 ↑/↓ | freq +/- | (무시)
STOP 짧게 | 메인 복귀 | 변경 취소 → 메뉴 (v3.9) | 메뉴 복귀
STOP ≥2s | 메인 복귀 | 변경 취소 → 메뉴 (길이 무관) | 메인 복귀
SELECT / PROG | 무시 | 무시 | 무시

## ⏰ 시간 동기화 + 영속화 (v3.6)

기능 | 방식 | 간격 | 비고
SNTP 동기화 | pool.ntp.org (IPv6 via Thread BR) | 1 시간 | esp_sntp_set_sync_interval(3600000)
NVS 영속화 (주기 저장) | nvs_set_i64("last_epoch") | 5 분 | ~105k writes/year (NVS 한계 100k 안전 margin)
NVS 영속화 (SNTP 콜백) | SNTP 동기화 직후 | 1 시간 | 정확한 시간 즉시 저장
리셋 후 복원 | _init_rtc_from_build_time() | 부팅 시 1회 | NVS 값 + 2.5분 → 빌드시간 비교 후 큰 값 사용

부팅 로그 예시:

I (612) MAIN: RTC 초기화 [BUILD] (KST-9, 빌드+95s 보정): 2026-05-15 11:07:40   ← 첫 부팅
I (612) MAIN: RTC 초기화 [NVS] (KST-9, 빌드+95s 보정): 2026-05-15 14:23:15   ← 리셋 후

I (...) MAIN: [TIME] NVS 저장: epoch=1778821395                              ← 5분마다
I (...) MAIN: [TIME] SNTP 동기화 → epoch=1778821400                          ← 1시간마다 (BR 필요)

## 🧵 SmartThings 연결 — Matter over Thread (v3.0~v3.6)

항목 | v2.x (WiFi) | v3.0 (Thread)
물리 계층 | WiFi 2.4 GHz (802.11 b/g/n) | 802.15.4 (ESP32-C6 내장)
네트워크 자격증명 | SSID + 비밀번호 (사용자 입력) | commissioner 가 BLE 로 자동 주입
SoftAP 프로비저닝 | "Somfy-XXXX" SSID + HTTP | 불필요 (BLE 커미셔닝만)
외부 인프라 | 가정용 WiFi 라우터 | Thread Border Router 필수
IP | IPv4 (DHCP) | IPv6 only (link-local + ULA)
전력 (idle) | ~75 mA (Modem-sleep) | ~5 mA (MTD always-listen)
커미셔닝 절차 | SmartThings 앱 → BLE → WiFi 자격증명 | SmartThings 앱 → BLE → Thread dataset
SW6 5초 롱프레스 | WiFi 자격증명 erase + SoftAP 재시작 | Thread dataset erase + 커미셔닝 윈도우 재오픈
OLED 아이콘 | WiFi 3-bar 신호 | Thread 메시 노드 + 이웃

### 필요한 Thread Border Router (택1)

- SmartThings Hub v3+ (Aeotec) — 가장 권장 (Thread + Matter 통합)
- Apple HomePod mini / Apple TV 4K (2nd gen+) — Apple Home 사용 시
- Google Nest Hub Max / Nest Hub (2nd gen) — Google Home 사용 시
- Amazon Echo 4th gen+ (Thread 지원 모델)
- eero 6+/Pro 6/Pro 6E 라우터 (Matter 인증)
- 또는 자체 빌드: esp-idf/examples/openthread/ot_br 으로 ESP32-S3+C6 보드 활용

### 커미셔닝 흐름 (사용자 절차)

1. 디바이스 부팅 → OLED 에 "Thread" 화면 (BLE 광고 시작)
2. SmartThings 앱 → 디바이스 추가 → OLED 의 기기 고유 QR 스캔/코드 입력 (eFuse 산출, 기기마다 다름)
3. 스마트폰이 BLE 로 ESP32-C6 와 연결
4. SmartThings Hub 가 Thread dataset (네트워크 키 등) 을 BLE 로 전송
5. ESP32-C6 가 Thread 네트워크에 부착 → OLED 아이콘 활성화
6. Matter 커미셔닝 완료 → BLE 광고 종료, 일반 Thread 통신 사용

## 📋 PCB 변형 (5종, v2.0 적용)

변형 | 폼팩터 | 전원 | 인코더 | 특수
base | USB-C 직결, 단일 PCB | USB 5V 전용 | EC11 (수직) | —
_v | 분리형 단일 PCB | 600mAh 배터리 + USB 충전 | EC05 (수평) | + SW5 보조 STOP
_h | 통합형 단일 PCB | 600mAh 배터리 + USB 충전 | EC11 (수직) | —
_v2 | 2-board sandwich (분리형) | 600mAh 배터리 + USB 충전 | EC05 (수평) | + SW5, VS1 진동
_h2 | 2-board sandwich (통합형) | 600mAh 배터리 + USB 충전 | EC11 (수직 SMD) | VS1 진동

자세한 비교 + 발주 가이드: kicad/FINAL_REPORT.md 참조. v2.0 변경: V2_0_STATUS.md.

## 📐 PCB 설계 사양 (v2.0)

항목 | 값 | 비고
보드 두께 | 1.0mm | v1.x 1.6mm 에서 변경
레이어 | 2 layer (F.Cu / B.Cu)
동박 두께 | 1oz (0.035mm)
유전체 | FR4, Er=4.5, 0.91mm | JLCPCB 표준 (1MHz Er=4.6 → 447MHz Er≈4.5 보정)
일반 트레이스 | 0.15mm (6mil) | 제조 최소, 클리어런스도 0.15mm
ANT_447M 트레이스 | 1.712mm | Hammerstad-Jensen microstrip 50Ω @ 447MHz
비아 (외경/드릴) | 0.8 / 0.4mm
에지 클리어런스 | 0.5mm

참고: kicad/_apply_v1_2_transline.py — KiCad Calculator Transline 동등 microstrip 50Ω 계산.

## 📋 OLED 화면 회전

디바이스를 거꾸로 들고 사용하는 경우를 위해 OLED 표시가 자동으로 180° 회전됩니다.

- 구현: oled_ui.c의 _fb_flush() 내부에서 매 프레임 (50ms, 20fps) 변환
- 변환 = 페이지 역순 + 컬럼 역순 + 8비트 역순 (총 360 byte 처리, <50µs CPU)
- 비활성화: #define OLED_ROTATE_180 0 후 재빌드

## 🔧 조립 주의사항 (v2.0)

- CC1101은 3.3V 전용 — 5V 연결 시 즉시 파손됩니다.
- CC1101 핀맵 (네이티브 FSPI): SCK=IO6, MOSI=IO7, MISO=IO2, CSN=IO4. PCF8574 SDA=IO19, SCL=IO18 (bit-bang).
- 외부 풀업 필수:
  - PCF8574 SDA (IO19) ↔ +3V3: 4.7kΩ
  - PCF8574 SCL (IO18) ↔ +3V3: 4.7kΩ
  - PCF8574 ~INT (IO17) ↔ +3V3: 10kΩ ★ v2.0 신규
- PCF8574 A0/A1/A2 를 모두 GND에 연결해야 I2C 주소가 0x20 이 됩니다.
- OLED는 HP I2C0 (IO0/IO1, 보드 내장), PCF8574 는 software bit-bang (IO18/IO19) — 핀 충돌 없음.
- v2.0 에서 LP_I2C0 는 사용 안 함 (LP_GPIO6/7 핀 제약 해제 → 라우팅 자유도 ↑).
- 각 VCC 핀 근처에 100nF 디커플링 캐패시터를 배치하면 노이즈가 줄어듭니다.
- 이 펌웨어는 Matter over Thread (802.15.4) — WiFi 미사용. Thread Border Router(SmartThings Hub v3+/Apple TV 4K/Nest Hub 2nd 등)가 필요합니다.
- PCB 설계 파일: kicad/somfy_blinds[_v|_h|_v2|_h2].kicad_* 5종.
- v2.0 적용 스크립트: kicad/_apply_v2_0_sch_rewire.py (스키매틱) + _apply_v2_0_pcb_nets.py (PCB).
- 발주용 거버: kicad/gerber/somfy_blinds*.zip — v2.0 재라우팅 후 재생성 필요.

## ⚙ 펌웨어 / 드라이버 변경 이력

- v3.6 — UX 개선 + 시간 영속화 + 버그 수정 (2026-05-15):
  - oled_ui.c — 액션 텍스트 라벨 (UP/DN/STOP/B1/ALL) 제거; 틸트 모션을 3장 블라인드 슬랫 회전으로 재설계 (half_w=18, max tilt=8px)
  - main.c — SELECT 모션 중단+순환; 시간 영속화 (5분 NVS 저장 + SNTP callback); SmartThings 명령 wake + 모션
  - main.c — _init_rtc_from_build_time(): NVS 우선 복원, BUILD/NVS 출처 로그
  - matter_blinds.cpp — ★ 핵심 버그 수정: app_attribute_cb fall-through 제거 (handled flag) → 연속 버튼 입력 시 갑작스러운 STOP 모션 / 가짜 STOP RF 제거
  - SNTP: esp_sntp_set_sync_interval(3600000) + 동기화 콜백으로 NVS 즉시 저장
- v3.5 — 설정 메뉴 정리 (2026-05-15): 숫자 prefix 제거, Cancel 첫 항목으로 이동, "Matter Pair"/"Thread Rst" 풀 표시
- v3.4 — 진동 wake (2026-05-15): VIBE 감지 시 메인 루프가 _exit_screensaver/sleep 호출 → 자동 활성 복귀
- v3.3 — Thread SED + PM (2026-05-15): CONFIG_ENABLE_ICD_SERVER=y → esp-matter 가 Thread device type 을 Sleepy End Device 로 자동 설정; CONFIG_PM_ENABLE=y + tickless idle
- v3.2 — 전원 정책 (2026-05-14): USB 연결 3분 → 화면 보호기; 배터리 1분 → 절전. _is_usb_powered() 휴리스틱 (CHG_STAT)
- v3.1 — 설정 메뉴 (2026-05-14): 4-item 메뉴 + 상태머신 (SETUP_MENU_SCR / FREQ_EDIT / MATTER_PAIR / THREAD_RESET); PROG long-press Matter/Thread 기능 메뉴로 이관
- v3.0 — WiFi → Thread (2026-05-13):
  - main/wifi_provision.{h,c} 삭제 → main/thread_provision.{h,c} 신규
  - main/main.c — esp_wifi.h/esp_wifi_set_ps() 제거, OpenThread 자동 관리
  - main/matter_blinds.cpp — kThreadStateChange / kThreadConnectivityChange 이벤트 핸들러 추가
  - main/oled_ui.{h,c} — OLED_STATE_WIFI_PROV → OLED_STATE_THREAD_PROV, WiFi 신호바 → Thread 메시 아이콘
  - sdkconfig.defaults — CONFIG_ESP_WIFI_* 제거, CONFIG_OPENTHREAD_ENABLED=y + CONFIG_CHIP_ENABLE_OPENTHREAD=y 추가
  - BLE NimBLE 는 Matter 커미셔닝 용으로 유지
- v2.0 — 핀 재배치 + bit-bang I2C (2026-05-13):
  - somfy_config.h — CC1101 SPI (IO4-7), PCF8574 I2C (IO18/19), wake sources (IO3/16/17)
  - button_handler.c — software bit-bang I2C 50kHz
- 빌드 결과: GNPE somfy_blinds.bin ≈0x1A7020 bytes (OTA 슬롯 1.875 MB) ✅ v2.0 0x1F4990 (WiFi) → v3.0 0x1E6940 (Thread) → v3.3 0x1CE5A0 (SED+PM) → v3.6 0x1CEB20 → v3.9 ~0x1A7020 (현재)

Somfy RTS Wood Blind Controller v3.9 (편집 UX: SETUP 짧게=저장 / STOP=취소) | 배선도 최종 갱신: 2026-06-18 | KiCad 회로도: kicad/somfy_blinds*.kicad_sch
버전 이력: v2.0 (핀 재배치) → v3.0 (Thread) → v3.1 (설정 메뉴) → v3.2 (전원 정책) → v3.3 (SED+PM) → v3.4 (진동 wake) → v3.5 (메뉴 정리) → v3.6 (UX + 시간 + 버그 수정) → v3.9 (편집 UX)

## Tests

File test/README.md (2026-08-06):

# 테스트 (재사용 가능)

ESP32-C6 Somfy RTS 컨트롤러 v3.5 의 **가상(on-target, 온에어 불필요)**
테스트 모음. 케이스별로 정리되어 있고, 빌드 스크립트를 포함하여 나중에
다시 활용할 수 있다.

## 구조

```
test/
├─ README.md
├─ build_test.ps1            테스트 펌웨어 빌드/플래시 (build_test/ 에 산출)
└─ somfy_cases/
   ├─ somfy_selftest.h
   ├─ somfy_selftest.c       [virtual] 블라인드 1~5 × 케이스별 가상 검증
   ├─ somfy_onair_test.h
   └─ somfy_onair_test.c     [onair]   실제 CC1101 온에어 RF 송신 검증
```

## 두 가지 테스트 모드 (`-Mode`, 택일·별도 빌드)

| 모드 | 빌드 플래그 | 내용 | RF |
|---|---|---|---|
| `virtual` (기본) | `-DSOMFY_SELFTEST=1` | 7바이트 프레임 정합성 + **ALL 블록 라우팅**(가상) | 불필요 |
| `onair` | `-DSOMFY_ONAIR_TEST=1` | 실제 CC1101 로 진짜 신호 송신 | **필요** |

### onair 케이스 (실제 신호 발생)

| Phase | 내용 |
|---|---|
| A | CC1101 SPI 통신/칩 확인 (PARTNUM/VERSION) |
| B | 6개 주파수 + 기기 설정 주파수로 변경 → FREQ 레지스터 라이트백 + 실제 캐리어(TX state) 송신 검증 |
| C | 가상 버튼(UP/DOWN/MY/PROG) × 블라인드 1~5 번갈아 실제 변조 송신 |
| D | ALL 선택 시 5개 블라인드 동시(순차) 실제 송신 + PROG 차단 정책 검증 |

> onair 는 실제 RF 를 공중에 송신한다. 공유 인스턴스
> `g_cc1101/g_somfy/g_mgr` (app_main.cpp Phase2 초기화분)을 그대로 사용하며
> NVS·실제 롤링코드는 건드리지 않는다(로컬 복제). CC1101 하드웨어가
> 미응답이면 명확한 진단 로그와 함께 중단(`결과: 0/0, 하드웨어 미준비`).

- 정상 펌웨어 빌드(`build/`)와 **분리된 `build_test/`** 에 산출 → 테스트
  펌웨어가 보존되어 재활용 가능. 검증된 루트 `sdkconfig` 를 공유한다.
- `-DSOMFY_SELFTEST=1` 일 때만 테스트 코드가 컴파일/실행된다. 일반
  빌드(`build.ps1`)에는 전혀 포함되지 않는다.

## 케이스 (블라인드 1~5 각각)

| 케이스 | 모델링한 RTS 절차 |
|---|---|
| 신규 등록 | PROG(long) |
| 상한 설정 | PROG → UP → MY |
| 하한 설정 | PROG → DOWN → MY |
| 복사 | 원격 식별자(주소/주파수/롤링) 복제 후 동일 주소 전송 검증 |
| 위치 기억 | MY(long, favorite 기억) |

검증 항목(프레임별): 커맨드 nibble, 24bit 주소, 롤링코드(스텝마다 +1),
체크섬 nibble. CC1101/RF/NVS 를 건드리지 않는 순수 가상 검증
(`somfy_rts_test_build_frame()`).

### ALL(블록) 라우팅 케이스 (`_all_route_tests`)

`blind_manager_get_targets()`(실제 함수) + `somfy_app.c` `_do_rf_send` 라우팅을
재현해 **실제 산출 주소(eFuse)** 로 검증한다. 채널 수에 따라 자동(H2 3채널=1블록,
C6 8채널=2블록):

| 검증 | 내용 |
|---|---|
| 주소 규칙 | `F0` prefix(carry 없음) · 채널 등차 `0x2700` · `ALL=base+4×0x2700` · base mid<0x27 |
| ALL + UP/DOWN/MY | 블록별 ALL 주소로 송신(블록 수만큼) + **모든 채널 position 정확히 1회** 갱신(100/0/50) |
| ALL + PROG | **차단**(송신 0 — ALL 은 PROG 없음) |
| 개별 채널 | 선택 채널만 송신/갱신, 나머지 미변경. 개별+PROG 는 정상 송신 |
| 포인터 판별 | 채널(`off<MAX`) vs ALL 블록(`off≥MAX`) 구분 |

매니저는 `blind_manager_test_populate()`(테스트 전용, **NVS 미접근**)로 채운다.
이 훅과 라우팅 케이스는 `SOMFY_SELFTEST`/`SOMFY_ONAIR_TEST` 빌드에서만 컴파일되어
**프로덕션 `.bin` 은 불변**이다(GNPE byte-identical 보존).

## 실행

```powershell
# 가상 프레임 검증 (기본)
./test/build_test.ps1 -Action build -Mode virtual
./test/build_test.ps1 -Action flash -Mode virtual -Port COM3

# 실제 CC1101 온에어 RF 송신 검증
./test/build_test.ps1 -Action build -Mode onair
./test/build_test.ps1 -Action flash -Mode onair -Port COM3
```

부팅 직후 표준 레벨 로깅(esp_log)으로 출력:
- `I (SELFTEST) [PASS] 블라인드N <케이스>`
- `E (SELFTEST) [FAIL] 블라인드N <케이스>`
- `W (SELFTEST) ===== 결과: X/Y PASS, Z FAIL =====`

전체 통과 시 `Z FAIL` = 0.

## 일반 펌웨어로 복귀

테스트는 별도 `build_test/` 라 일반 빌드에 영향 없음. 평소 운영
펌웨어는 그대로:

```powershell
./build.ps1 -Action build
./build.ps1 -Action flash -Port COM3
```

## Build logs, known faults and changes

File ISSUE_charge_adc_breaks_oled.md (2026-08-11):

# [전부 해결됨] 배터리/충전 관련 이슈 모음 (2026-08-11)

> 이 문서는 **GitHub 이슈가 아니라 리포지토리 내 기록**이다(`gh` CLI 미설치로 등록 못 함).
> GitHub 에 올리려면 이 내용을 그대로 붙여 넣으면 된다.

배터리·충전 도메인에서 이번에 해결한 네 건을 시간순으로 기록한다.
전부 실기에서 재현 → 원인 확정 → 수정 → 재확인까지 마쳤다.

| # | 증상 | 상태 |
|---|---|---|
| 1 | 충전률 측정을 켜면 OLED 가 몇 분 내 고착 | ✅ 해결 |
| 2 | 배터리 미연결인데 **78%** 로 표시 | ✅ 해결 |
| 3 | USB 없이 배터리만 연결하면 **부팅 중 멈춤/반복 재부팅** | ✅ 해결 |
| 4 | 배터리 구동 시 % 가 **74~84% 로 튐** | ✅ 해결 |

---

## 1. 충전률 측정이 OLED 비트뱅 I2C 전송을 파괴

**증상**: 배터리 충전률 측정을 켜면 수 분 내에 OLED 화면이 멈춘다. SSD1306 은 4핀
모듈이라 RES 핀이 없어, 한 번 고착되면 ESP32 리셋·재플래시로도 풀리지 않았다.

**근거 (실기 이분 탐색, COM7 / xiao-c6)**

| 조건 | 결과 |
|---|---|
| 충전측정 ON + 버튼 RF ON | 수 분 내 화면 멈춤 |
| 충전측정 OFF + 버튼 RF OFF | 멈춤 없음 |
| **충전측정 OFF + 버튼 RF ON** | **멈춤 없음** → RF 는 무죄 |

**원인 — 락이 전송 경로를 다 덮지 못했다.** ESP32-C6 는 싱글코어라 "동시 실행"이
아니라 **선점**이 파괴 기전이다.

    btn_handler 10  >  somfy_app 4  >  oled_ui 3
                          ↑ ADC + 화면OFF/ON      ↑ OLED 비트뱅 flush

somfy_app(prio 4)이 oled_ui(prio 3)를 선점한다. 비트뱅은 **CPU 가 곧 클럭**이라
선점당한 전송은 SCL/SDA 가 중간 상태로 수백 µs 멈춰 SSD1306 상태머신이 고착된다.
`adc_oneshot_read()` 의 `portENTER_CRITICAL` 은 **악화 요인**이지 근본이 아니었다.

`oled_ui_i2c_lock()` 이 `_fb_flush` 만 감싸서 아래 두 경로가 **무방비**였다:

| 무방비 경로 | 호출자 | 빈도 |
|---|---|---|
| `_oled_send_cmds()` ← `oled_ui_set_display_on()` | somfy_app | 화면 자동 OFF/ON **10초마다** |
| `_bbo_probe()` ← `_oled_try_detect()` | flush 의 early-return 경로(락 잡기 **전**) | 미검출 시 5초마다 |

**수정**
1. 락 범위를 **`_bbo_write()` 전송 함수 자체로 이동** — 호출 지점이 늘어도 자동 보호
2. **재귀 뮤텍스로 변경** — `_fb_flush` 가 바깥 락을 쥔 채 `_bbo_write` 를 부르므로
   일반 뮤텍스면 자기 자신을 기다려 **즉시 데드락**
3. 뮤텍스 생성을 `oled_ui_init()` **맨 앞**으로 — NULL 이면 무보호로 통과하던 구간 제거
4. 락 타임아웃(200 ms) 시 **전송은 진행**하고 `g_bbo_lock_to_cnt` 로만 계수
5. `TEMP_NO_CHARGE` 1 → **0** (충전측정 재활성)

**측정 주기(5초)·표본 수(8회)는 바꾸지 않았다.** 줄이면 `_nobat_track` 의
"5분 창 / 반쪽당 30표본" 노이즈 상쇄 가정이 깨져 배터리 미연결 오판이 생긴다.

**검증**
- 시뮬: `sim/tools/adc_oled_mutex_sim.py` (8시드 × 10분) — 수정 전 **6/8회 고착
  (최빠른 80초)** → 수정 후 손상 0 / 고착 0 / 배터리 측정 952/952
- 실기 장시간(COM7): 콘솔 `cyc` 로 화면 100% 부하 + ADC 5초 주기 병행
  **4시간 45분 / 전송 257,562건 / 실패 0 / lockTO 0**, `present` 284샘플 전부 1,
  패닉·재부팅·워치독·버스복구 0건, free heap Δ-80 B

---

## 2. 배터리 미연결인데 78% 로 표시

**원인**: 배터리를 빼도 충전 IC(MCP73831)가 BAT+ 를 무부하로 **약 3,970 mV** 로 띄우는데,
이 값이 OCV-SoC 곡선상 정확히 78% 다.

```
3850mV=60%, 3980mV=80% 구간 보간
60 + 20 × (3970-3850)/(3980-3850) = 78.4% → 78%
```

**전압만으로는 실제 배터리 78% 와 구분 불가.** 유일한 단서는 "전압이 오르는가"
(무배터리 float = 안 오름 / 충전 중인 셀 = 오름)이고, 이 판정은 5분 창이 차야 나온다.
→ 부팅 후 **5분 23초** 동안 78% 가 보였다(실기 로그로 확인).

```
W (322394) [BAT] 배터리 판정: 미연결 → 0% 표시
           전반 3971mV(n30) 후반 3969mV(n30) 상승 -2mV (창O, 안오름O, USB=1)
```

**수정**: 첫 판정 전에는 `--%` 표시(`BAT_PCT_UNKNOWN`). 단 **애매할 때만** 숨긴다 —
float 창(3940~4010 mV) 밖이거나 USB 미연결이면 배터리 존재가 자명하므로 즉시 % 표시.
실제 배터리를 꽂은 사용자는 거의 대기가 없다.

**★창(5분)을 줄이면 안 된다.** 충전 상승률 ≈9.3 mV/5분 vs 판정 문턱 4 mV:

| 창 | 전반/후반 평균차 | 판정 |
|---|---|---|
| 3분 | 2.8 mV | **오판**(충전 중인 배터리를 "미연결"로) |
| 5분 | 4.7 mV | 안전 |

검증: `sim/tools/bat_pct_display_sim.py` (4시나리오 + 창 단축 위험표)

---

## 3. USB 없이 배터리만 연결하면 부팅 중 멈춤 / 반복 재부팅

**증상**: USB 를 빼고 배터리만 연결하면 부팅 화면에서 멈추고, 40초~1분마다 재부팅.
메인 화면에 도달하지 못한다. USB 를 꽂으면 정상 — 그래서 시리얼 로그를 볼 수 없다.

**진단 방법**: 전원이 끊겨도 남는 **NVS 부팅 단계 기록**(`main/boot_diag.c`)을 만들었다.
RTC RAM 은 배터리를 빼면 지워지므로 못 쓴다. app_main 경로와 somfy_app 경로를 **따로**
세고(두 태스크가 동시 진행하므로 단일 카운터로는 구분 불가), 실패한 부팅은 별도 키에
**영구 보관**한다(정상 부팅이 덮어쓰지 않도록). `bd` 콘솔 명령으로 언제든 조회.

**결정적 기록**

```
직전 부팅: ★부팅 미완료
  app_main = 8 (콘솔 명령 등록 완료)
  somfy_app = 3 (oled_ui_init 직전)  sub = 10 (OLED 검출 성공)
  uptime = 1,193ms
  bat = 3994 / 최저 3994mV       ← 배터리 정상, 처짐 0
  리셋사유 = 전원투입             ← 브라운아웃/패닉/워치독 아님
```

**탈락한 가설들** (전부 데이터로 배제)

| 가설 | 탈락 근거 |
|---|---|
| 전원 부족/브라운아웃 | 배터리 4.02 V, **최저치도 동일**(사그 0). C6 는 브라운아웃을 정확히 보고하는데 2.92 V 로 올려도 한 번도 안 찍힘 |
| Task WDT | 타임아웃 5초라 40~60초 주기와 불일치 |
| BAT_ADC 로직 | 실패 기록 하나가 `somfy_app=0`(태스크 미실행) — 코드가 아예 실행 안 됨 |
| I2C 스캔 NULL 핸들 | `sub=10`(검출 성공)이라 그 경로 미실행 |

**원인**: `app_main`(prio 1)과 `somfy_app`(prio 4)이 **동시에** 멈췄다. 우선순위가 다른
두 태스크가 같이 굳는다면 공통 자원이 막힌 것이고, 그건 **콘솔 출력**뿐이다.

```cpp
// esp_matter_console.cpp — CHIP shell 을 우선순위 5 로 띄운다
xTaskCreate(&ChipShellTask, "console", ..., 5, NULL);   // RunMainLoop()
```

```c
// esp_rom_usb_serial.c — 줄바꿈마다 호스트를 기다린다
void esp_rom_usb_serial_putc(char c) {
    usb_serial_device_tx_one_char(c);
    if (c == '\n') usb_serial_device_tx_flush();
}
```

보조 콘솔이 USB-Serial-JTAG(`CONFIG_ESP_CONSOLE_SECONDARY_USB_SERIAL_JTAG`)이라,
USB 호스트가 없으면 이 ROM 함수가 대기한다. **prio 5** 태스크가 여기서 늘어지면
somfy_app(4)·oled_ui(3)를 굶겨 부팅이 끝나지 않는다. USB 를 꽂으면 호스트가 FIFO 를
비워 즉시 끝나므로 증상이 사라진다 — 관측과 정확히 일치.

**수정**: **VBUS 가 실제로 있을 때만** CHIP shell 콘솔을 시작한다(`app_main.cpp`
`_usb_vbus_present()`). 콘솔은 개발용이고 `tx`/`sel`/`cyc`/`bd` 도 USB 전용이라
배터리 단독 동작에는 불필요하다.

판정에 `usb_serial_jtag_is_connected()` 를 쓰지 않은 이유: 그 API 는 SOF 패킷 기반이라
부팅 ~1초 시점엔 열거가 안 끝나 false 가 나올 수 있고, 그러면 **USB 개발 중에도 콘솔이
사라진다**. VBUS 분압(GPIO17, `BOARD_CHG_STAT_ACTIVE_HIGH=1`)은 꽂는 즉시 HIGH 다.

**결과**: 배터리 단독 정상 부팅 확인.

**부수 수정**: `_oled_i2c_scan()` 이 비트뱅 모드에서 `s_dev._i2c_bus_handle == NULL` 로
`i2c_master_probe` 를 112번 부르고 있었다(크래시는 없지만 에러 로그 112줄).
비트뱅 프로브로 교체했다 — 이번 증상의 원인은 아니었지만 같은 함정을 만들 수 있는 코드다.

---

## 4. 배터리 구동 시 % 가 74~84% 로 튐

**증상**: 81 → 82 → **74** → 84 → 81 → 83 → 81 → 82 %

**원인**: USB 전원일 땐 레일이 단단해 전압이 거의 안 변했다. 배터리로 바꾸면 BLE 광고·
RF 송신 순간 **실제로** 전압이 떨어진다. 5초 주기 측정이 그 순간에 걸리면 한 점이 크게
낮게 찍힌다. OCV 곡선상 이 구간은 **1% ≈ 10 mV** 라 100 mV 만 흔들려도 10%p 가 움직인다.

`_read_bat_mv()` 의 8회 평균은 수십 µs 안에 끝나 **같은 순간을 8번 재는 것**이라
ADC 노이즈만 줄일 뿐 부하 변동은 못 거른다. 게다가 평균은 이상치에 통째로 끌려간다.

**수정 (표시 경로에만)**
1. **중앙값 5주기** — 송신 순간에 걸린 점을 통째로 버린다(평균과 달리 안 끌려감)
2. **EMA(α=1/4)** — 남은 흔들림을 시간축으로 눌러 표시가 안 튀게 한다

`_nobat_track` 에는 **원본 값**을 준다 — 그쪽은 5분 창 30표본 통계라 평활하면
이슈 #2 의 판정 가정이 깨진다. 측정 주기·표본 수도 그대로 둔다.

**★EMA 를 1/16 mV 단위로 누적한다.** C 의 정수 나눗셈은 0 쪽으로 절단하므로,
1 mV 단위로 `ema += (med-ema)/4` 를 쓰면 차이가 1~3 mV 일 때 몫이 0 이 되어
**EMA 가 영영 안 움직인다**(고착). 파이썬의 `//` 는 내림이라 시뮬레이터를 그냥
옮겼으면 이 버그를 못 봤을 것이다 — `sim/tools/bat_pct_smooth_sim.py` 가 C 절단을
흉내내 잡아냈다.

**검증** (`sim/tools/bat_pct_smooth_sim.py`)

| 지표 | 원본 | 평활 |
|---|---|---|
| 진폭 | 19 %p | **9 %p** |
| 주기간 평균 변동 | 4.09 %p | **0.38 %p** |
| 최저값(송신 강하 노출) | 66 % | **75 %** |
| 방전 추종 지연 | — | 2 %p 이내 |

---

## 참고 — 이 도메인에서 되풀이된 함정

- **로그 인코딩은 캡처 경로마다 다르다.** pyserial 직접 캡처 = UTF-8,
  빌드 로그(`logs/*.log`) = CP949. 틀리게 디코드하면 한글 에러가 0건으로 오독된다.
- **"실패 0"은 정상의 증거가 아니다.** OLED 미검출이면 flush 를 건너뛰어 에러도
  안 생긴다. `present=1` 과 전송 카운터 증가를 함께 볼 것.
- **부팅 ~100 ms 구간 로그는 USB-JTAG 이 버린다.** 진단값은 나중에 다시 출력해야 한다
  (실제로 `boot_diag` 첫 시험에서 핵심 줄만 통째로 유실됐다).
- **진단 기록을 한 칸만 두면 증거가 날아간다.** 실패 직후의 정상 부팅이 덮어썼다
  (`boot_diag` 를 별도 `fail` 키 보관으로 재설계한 이유).
- **리셋 사유는 "그 부팅이 시작된 이유"** 지 "끝난 이유"가 아니다. 헷갈리면 오진한다.

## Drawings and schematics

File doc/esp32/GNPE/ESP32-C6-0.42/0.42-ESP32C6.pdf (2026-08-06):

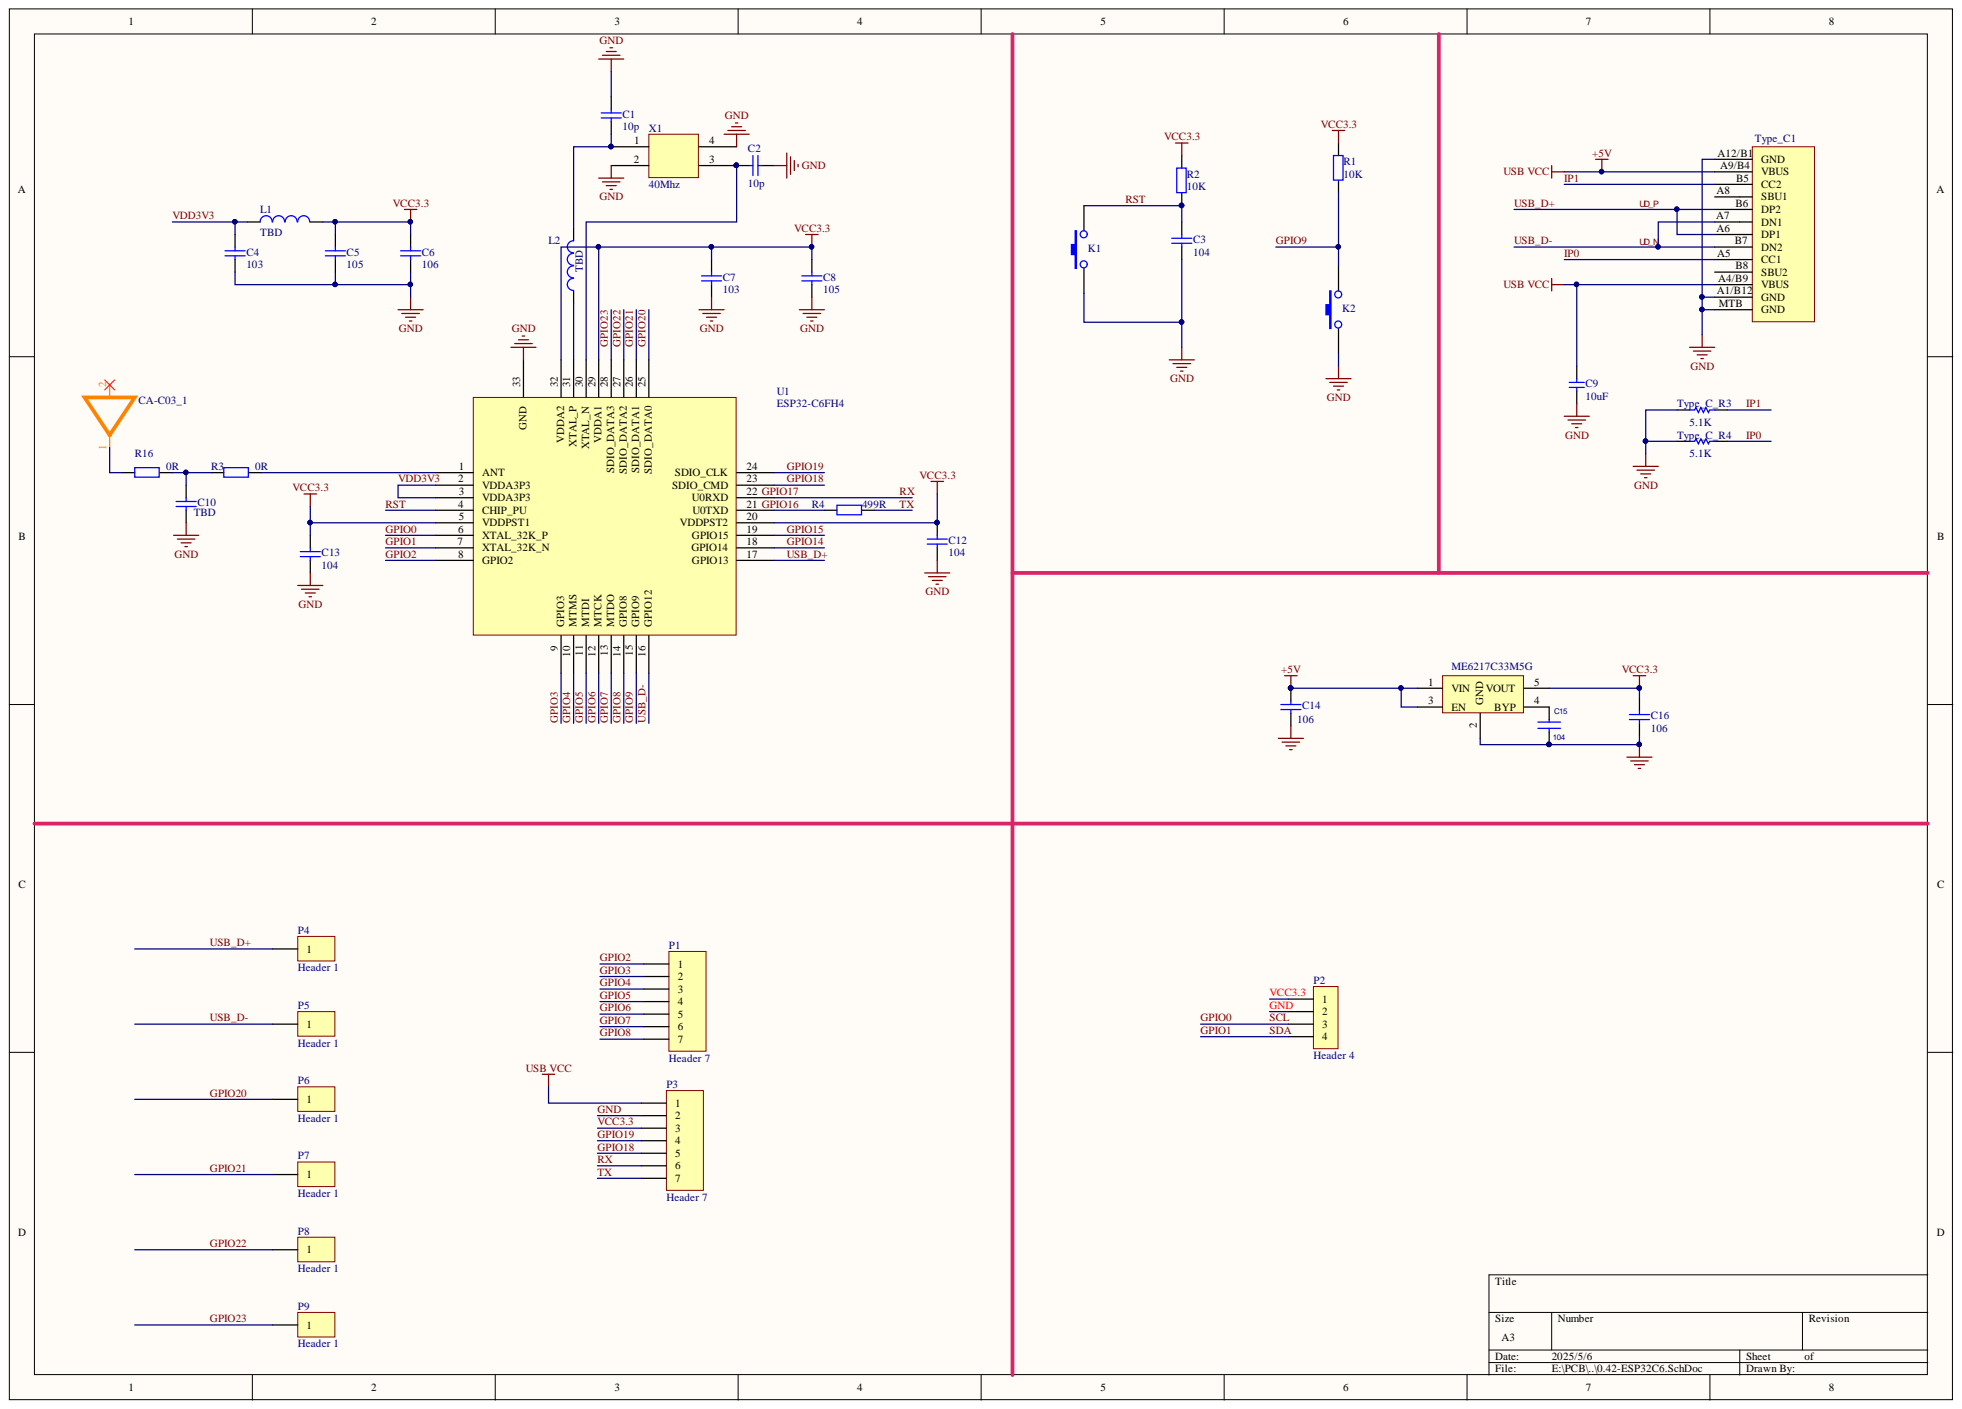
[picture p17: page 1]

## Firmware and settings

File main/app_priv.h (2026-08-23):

/*
 * app_priv.h — 앱 드라이버 내부 공유 선언.
 * Somfy RTS 블라인드 컨트롤러 (ESP32-H2/C6) v3.5. Public Domain (CC0). 무보증.
 */

#pragma once

#include <esp_err.h>
#include <esp_matter.h>

#if CHIP_DEVICE_CONFIG_ENABLE_THREAD
#include "esp_openthread_types.h"
#endif

/** Standard max values (used for remapping attributes) */
#define STANDARD_BRIGHTNESS 100
#define STANDARD_HUE 360
#define STANDARD_SATURATION 100
#define STANDARD_TEMPERATURE_FACTOR 1000000

/** Matter max values (used for remapping attributes) */
#define MATTER_BRIGHTNESS 254
#define MATTER_HUE 254
#define MATTER_SATURATION 254
#define MATTER_TEMPERATURE_FACTOR 1000000

/** Default attribute values used during initialization */
#define DEFAULT_POWER true
#define DEFAULT_BRIGHTNESS 64
#define DEFAULT_HUE 128
#define DEFAULT_SATURATION 254

typedef void *app_driver_handle_t;

/** Initialize the light driver
 *
 * This initializes the light driver associated with the selected board.
 *
 * @return Handle on success.
 * @return NULL in case of failure.
 */
app_driver_handle_t app_driver_light_init();

/** Initialize the button driver
 *
 * This initializes the button driver associated with the selected board.
 *
 * @return Handle on success.
 * @return NULL in case of failure.
 */
/* ★2026-08-23 app_driver_button_init 제거 (app_driver.cpp 주석 참조) */

/** Driver Update
 *
 * This API should be called to update the driver for the attribute being updated.
 * This is usually called from the common `app_attribute_update_cb()`.
 *
 * @param[in] endpoint_id Endpoint ID of the attribute.
 * @param[in] cluster_id Cluster ID of the attribute.
 * @param[in] attribute_id Attribute ID of the attribute.
 * @param[in] val Pointer to `esp_matter_attr_val_t`. Use appropriate elements as per the value type.
 *
 * @return ESP_OK on success.
 * @return error in case of failure.
 */
esp_err_t app_driver_attribute_update(app_driver_handle_t driver_handle, uint16_t endpoint_id, uint32_t cluster_id,
                                      uint32_t attribute_id, esp_matter_attr_val_t *val);

/** Set defaults for light driver
 *
 * Set the attribute drivers to their default values from the created data model.
 *
 * @param[in] endpoint_id Endpoint ID of the driver.
 *
 * @return ESP_OK on success.
 * @return error in case of failure.
 */
esp_err_t app_driver_light_set_defaults(uint16_t endpoint_id);

#if CHIP_DEVICE_CONFIG_ENABLE_THREAD
#define ESP_OPENTHREAD_DEFAULT_RADIO_CONFIG()                                           \
    {                                                                                   \
        .radio_mode = RADIO_MODE_NATIVE,                                                \
    }

#define ESP_OPENTHREAD_DEFAULT_HOST_CONFIG()                                            \
    {                                                                                   \
        .host_connection_mode = HOST_CONNECTION_MODE_NONE,                              \
    }

#define ESP_OPENTHREAD_DEFAULT_PORT_CONFIG()                                            \
    {                                                                                   \
        .storage_partition_name = "nvs", .netif_queue_size = 10, .task_queue_size = 10, \
    }
#endif

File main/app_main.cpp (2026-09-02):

/*
 * app_main.cpp — Matter 코어 (노드/엔드포인트/WindowCovering delegate/
 *   OpenThread/커미셔닝) 및 CC1101·Somfy RTS·blind_manager 소유.
 * Somfy RTS 블라인드 컨트롤러(채널수 BLIND_MAX_COUNT — H2=3/C6=8). v3.5.
 * Public Domain (CC0). 무보증.
 */

#include <esp_err.h>
#include <esp_log.h>
#include <esp_system.h>
#include <esp_timer.h>
#include <esp_console.h>
#include <esp_pm.h>          /* esp_pm_dump_locks — 절전 진단 */
#include <string.h>
#include <stdlib.h>
#include <nvs_flash.h>

#include <esp_matter.h>
#include <esp_matter_console.h>
#include <esp_matter_ota.h>

#include "common_macros.h"
#include "log_heap_numbers.h"
#include "boot_diag.h"
#include <driver/gpio.h>
#include <esp_rom_sys.h>
#include "boards/board_select.h"   /* BOARD_PIN_CHG_STAT (VBUS 분압) */

#include <app_priv.h>
#include <app_reset.h>
#if CHIP_DEVICE_CONFIG_ENABLE_THREAD
#include <platform/ESP32/OpenthreadLauncher.h>
#endif

#include <app/server/CommissioningWindowManager.h>
#include <app/server/Server.h>
#include <app/clusters/window-covering-server/window-covering-delegate.h>
#include <app/clusters/window-covering-server/window-covering-server.h>
#include <app-common/zap-generated/cluster-objects.h>
#include <app-common/zap-generated/attributes/Accessors.h>

#ifdef CONFIG_ENABLE_SET_CERT_DECLARATION_API
#include <esp_matter_providers.h>
#include <lib/support/Span.h>
#ifdef CONFIG_SEC_CERT_DAC_PROVIDER
#include <platform/ESP32/ESP32SecureCertDACProvider.h>
#elif defined(CONFIG_FACTORY_PARTITION_DAC_PROVIDER)
#include <platform/ESP32/ESP32FactoryDataProvider.h>
#endif
using namespace chip::DeviceLayer;
#endif

#include <esp_matter_providers.h>     // esp_matter::set_custom_commissionable_data_provider
#include "efuse_commissionable.h"     // eFuse 기기 고유 discriminator/passcode

static const char *TAG = "app_main";
uint16_t light_endpoint_id = 0;

/* ── Somfy RTS / CC1101 RF 드라이버 ──
   이 인스턴스들을 C-linkage 전역으로 공개하여 somfy_app.c(OLED/버튼/메뉴)
   와 단일 인스턴스를 공유한다. g_commissioning_complete 는 somfy_app.c 의
   지연-시작 게이트가 폴링한다. */
extern "C" {
#include "cc1101.h"
#include "somfy_rts.h"
#include "blind_manager.h"
/* USB 호스트(SOF) 판정용 — 드라이버가 아니라 LL 레지스터만 읽는다. _usb_host_sof_present() 참조 */
#include "hal/usb_serial_jtag_ll.h"
cc1101_t        g_cc1101;
somfy_rts_t     g_somfy;
blind_manager_t g_mgr;
uint16_t        g_wc_ep_ids[BLIND_MAX_COUNT] = {0};
bool            g_rf_ready = false;
volatile bool   g_commissioning_complete = false;
/* somfy_app.c 진입점 (별도 태스크) */
void somfy_app_run(void *arg);
/* test/somfy_cases/oled_only_test.c — OLED 단독 부팅 테스트(OLED_ONLY_TEST 빌드) */
void oled_only_test(void);
/* matter_blinds_shim.cpp: SmartThings 명령 수신 시 somfy_app 의
   _matter_action_cb 호출 (OLED 깨우기/액션표시 + 단일 RF 큐). */
void matter_blinds_invoke_action_cb(uint8_t ep_idx, somfy_command_t cmd,
                                    uint8_t pos_pct, uint8_t oled_action,
                                    uint8_t step_count);
}
#define s_cc1101     g_cc1101
#define s_somfy      g_somfy
#define s_mgr        g_mgr
#define s_wc_ep_ids  g_wc_ep_ids
#define s_rf_ready   g_rf_ready

using namespace esp_matter;
using namespace esp_matter::attribute;
using namespace esp_matter::endpoint;
using namespace chip::app::Clusters;

/* ── WindowCovering Delegate ──────────────────────────────────────────
 *  SmartThings 의 열기/닫기/위치이동은 WindowCovering *명령*
 *  (UpOrOpen / DownOrClose / GoToLiftPercentage) 으로 온다. CHIP
 *  window-covering-server 는 이 명령을 받으면 Target* 속성을 갱신한 뒤
 *  Delegate::HandleMovement() 를 호출한다. delegate 미설정 시
 *  "WindowCovering has no delegate set" 로그만 찍히고 아무 동작 안 함
 *  (= 조작 불가). 여기서 delegate 가 Target → Somfy RF 로 변환하고
 *  Current* 속성을 갱신해 SmartThings 상태도 반영한다. */

/* ★ SmartThings 슬라이더 동기화 문제 해결:
 *  SmartThings WindowCovering UI 는 Lift/Tilt 슬라이더가 mirror 되어 어느
 *  한쪽만 만져도 양쪽 모두 새 target 으로 갱신 → HandleMovement(Lift) +
 *  HandleMovement(Tilt) 가 ~150ms 안에 연속 호출된다.
 *  → 두 RF 명령(UP/DOWN + TILT_UP/DOWN)이 큐에 쌓여 모터가 첫 명령으로
 *    주행 시작 직후 두 번째 명령에 의해 중단·tilt 짧은 step 으로 전환되어
 *    "조금밖에 안 움직임" 현상 발생.
 *  → 같은 EP 에서 400ms 이내 후속 호출은 companion 으로 보고 RF/OLED 모두
 *    SKIP. 사용자가 진짜로 두 슬라이더를 따로 만지려면 400ms 이상 텀을 두면
 *    됨(현실적으로 사용자 손가락 속도로는 충분히 분리된다).
 *  Open/Close 버튼: Lift 가 먼저 들어와 RF 송신 → Tilt 는 companion 으로 skip.
 *  Lift 슬라이더 단독: Lift 만 들어옴(또는 Tilt 가 동시에 와도 Lift 먼저 처리됨).
 *  Tilt 슬라이더 단독: Tilt 만 들어옴(또는 Lift 가 mirror 로 와도 Tilt 가 먼저). */
#define WC_COMPANION_GUARD_US  (400 * 1000)

static int64_t s_lastLiftUs = 0;
static uint16_t s_lastLiftEp = 0xFFFF;
static int64_t s_lastTiltUs = 0;
static uint16_t s_lastTiltEp = 0xFFFF;

/* ★ Stop 버튼(일시정지) 판별: SmartThings 가 movement 직후에도 HandleStopMotion
 *  을 자동 호출할 수 있어 무조건 MY 를 보내면 열기/닫기가 즉시 취소된다.
 *  마지막 movement 시각 + EP 를 기록해두고 HandleStopMotion 호출 시 그 이후
 *  일정 시간이 지났으면 = 사용자 명시 정지 → MY 송신, 그 안이면 = auto → 무시. */
static int64_t s_lastMoveUs = 0;
static uint16_t s_lastMoveEp = 0xFFFF;
#define WC_STOP_AUTOCALL_GUARD_US  (500 * 1000)   /* 500ms 이내 = auto-stop 무시 */

class SomfyWCDelegate : public chip::app::Clusters::WindowCovering::Delegate
{
public:
    CHIP_ERROR HandleMovement(chip::app::Clusters::WindowCovering::WindowCoveringType type) override
    {
        int idx = -1;
        for (int i = 0; i < BLIND_MAX_COUNT; i++) {
            if (s_wc_ep_ids[i] == mEndpoint) { idx = i; break; }
        }

        /* oled_action_t (oled_ui.h): 1=UP 2=DOWN 3=STOP 4=TILT_UP 5=TILT_DN */
        enum { OA_UP = 1, OA_DOWN = 2, OA_STOP = 3, OA_TUP = 4, OA_TDN = 5 };
        using namespace chip::app::Clusters::WindowCovering;
        if (type == WindowCoveringType::Tilt) {
            chip::app::DataModel::Nullable<chip::Percent100ths> tgt, cur;
            if (Attributes::TargetPositionTiltPercent100ths::Get(mEndpoint, tgt) == chip::Protocols::InteractionModel::Status::Success
                && !tgt.IsNull()) {
                uint16_t v = tgt.Value();
                /* ★ Tilt 슬라이더 = 슬랫 각도 조절 → 정품 Tilt 커맨드 사용
                 *  (UP/DOWN 이 아닌 TILT_UP/TILT_DOWN, cmd nibble 0xB).
                 *  방향: target > current = 슬랫 닫는 방향(TILT_DN), 그 반대=TILT_UP. */
                bool hasCur = (Attributes::CurrentPositionTiltPercent100ths::Get(mEndpoint, cur)
                                  == chip::Protocols::InteractionModel::Status::Success)
                              && !cur.IsNull();
                bool goDown;
                if (hasCur && cur.Value() != v) {
                    goDown = (v > cur.Value());
                } else {
                    goDown = (v >= 5000);
                }
                somfy_command_t cmd = goDown ? SOMFY_CMD_TILT_DOWN : SOMFY_CMD_TILT_UP;
                uint8_t oa         = goDown ? OA_TDN : OA_TUP;
                /* ★ Lift 가 최근(400ms 이내) 같은 EP 에서 호출됐으면 이번 Tilt 는
                 *  SmartThings mirror/Open/Close 의 companion 으로 보고 RF·OLED
                 *  모두 SKIP — Lift 모션을 끝까지 보장. Current* 는 슬라이더
                 *  UI 동기화를 위해 항상 갱신. */
                int64_t now = esp_timer_get_time();
                bool companion = (s_lastLiftEp == mEndpoint) &&
                                 (now - s_lastLiftUs) <= WC_COMPANION_GUARD_US;
                s_lastTiltUs = now;
                s_lastTiltEp = mEndpoint;
                if (companion) {
                    ESP_LOGI(TAG, "[WC] ep=%u TILT companion of recent LIFT — RF/OLED skip", mEndpoint);
                } else {
                    /* ★ Tilt 슬라이더 7단계 매핑 — 정품 tilt 리모컨이 0~100%
                     *  사이를 7 detent 로 처리한다(사용자 실측). 슬라이더 delta
                     *  에 따라 1~7 step burst 송신:
                     *    steps = round(|target-current| × 7 / 10000)
                     *    delta 1429 (=100/7%) → 1 step
                     *    delta 10000 (=100%)  → 7 steps
                     *  current 미상이면 50% 기준 차이로 fallback. 최소 1 보장. */
                    uint16_t curV = hasCur ? cur.Value() : 5000;
                    int diff = (int)v - (int)curV;
                    if (diff < 0) diff = -diff;
                    int steps = (diff * 7 + 5000) / 10000;   /* nearest 1/7 */
                    if (steps < 1) steps = 1;
                    if (steps > 7) steps = 7;
                    s_lastMoveUs = now;
                    s_lastMoveEp = mEndpoint;
                    ESP_LOGI(TAG, "[WC] ep=%u idx=%d TILT=%u cmd=%d oa=%u steps=%d",
                             mEndpoint, idx, v, cmd, oa, steps);
                    if (idx >= 0) {
                        matter_blinds_invoke_action_cb((uint8_t)idx, cmd,
                                                       (uint8_t)(v / 100), oa,
                                                       (uint8_t)steps);
                    }
                }
                Attributes::CurrentPositionTiltPercent100ths::Set(mEndpoint, tgt);
            }
        } else {
            chip::app::DataModel::Nullable<chip::Percent100ths> tgt, cur;
            if (Attributes::TargetPositionLiftPercent100ths::Get(mEndpoint, tgt) == chip::Protocols::InteractionModel::Status::Success
                && !tgt.IsNull()) {
                uint16_t v = tgt.Value();
                uint8_t pct = (uint8_t)(v / 100);
                /* ★ Lift 슬라이더 = 방향 기반 (Somfy RTS 는 위치 피드백 없어
                 *  중간값 정밀 도달 불가). target > current = 닫는 방향(DOWN),
                 *  target < current = 여는 방향(UP), 같으면 무동작.
                 *  → 사용자가 슬라이더를 어디로 끌든 모터는 그 방향대로 끝까지
                 *  주행한다(슬라이더 값은 trigger 일 뿐 도달점 아님). */
                bool hasCur = (Attributes::CurrentPositionLiftPercent100ths::Get(mEndpoint, cur)
                                  == chip::Protocols::InteractionModel::Status::Success)
                              && !cur.IsNull();
                somfy_command_t cmd;
                uint8_t oa;
                if (hasCur && cur.Value() != v) {
                    bool goDown = (v > cur.Value());
                    cmd = goDown ? SOMFY_CMD_DOWN : SOMFY_CMD_UP;
                    oa  = goDown ? OA_DOWN       : OA_UP;
                } else {
                    /* current 모름 또는 동일 — 끝값 기준 fallback */
                    if (pct >= 95)      { cmd = SOMFY_CMD_DOWN; oa = OA_DOWN; }
                    else if (pct <= 5)  { cmd = SOMFY_CMD_UP;   oa = OA_UP;   }
                    else                { cmd = SOMFY_CMD_MY;   oa = OA_STOP; }
                }
                /* ★ Tilt 가 최근 같은 EP 에서 호출됐으면 이번 Lift 는 mirror
                 *  companion 으로 보고 RF/OLED skip (Tilt 슬라이더 단독 조작 시
                 *  Lift 가 따라오는 케이스). 그 외엔 정상 Lift 처리 + 추후 Tilt
                 *  companion 가드용 timestamp 기록. */
                int64_t now = esp_timer_get_time();
                bool companion = (s_lastTiltEp == mEndpoint) &&
                                 (now - s_lastTiltUs) <= WC_COMPANION_GUARD_US;
                s_lastLiftUs = now;
                s_lastLiftEp = mEndpoint;
                if (companion) {
                    ESP_LOGI(TAG, "[WC] ep=%u LIFT companion of recent TILT — RF/OLED skip", mEndpoint);
                } else {
                    s_lastMoveUs = now;
                    s_lastMoveEp = mEndpoint;
                    ESP_LOGI(TAG, "[WC] ep=%u idx=%d LIFT=%u%% cmd=%d oa=%u", mEndpoint, idx, pct, cmd, oa);
                    if (idx >= 0) {
                        matter_blinds_invoke_action_cb((uint8_t)idx, cmd, pct, oa, /*step=*/1);
                    }
                }
                Attributes::CurrentPositionLiftPercent100ths::Set(mEndpoint, tgt);
            }
        }
        return CHIP_NO_ERROR;
    }

    CHIP_ERROR HandleStopMotion() override
    {
        int idx = -1;
        for (int i = 0; i < BLIND_MAX_COUNT; i++) {
            if (s_wc_ep_ids[i] == mEndpoint) { idx = i; break; }
        }
        /* ★ SmartThings "일시정지" → Somfy MY 송신.
         *  단, CHIP 서버가 open/close 명령 처리 직후에도 HandleStopMotion 을
         *  자동 호출할 수 있어 그 경우는 무시(아니면 모든 열기/닫기가 즉시
         *  취소됨). 마지막 movement 시각과 같은 EP 면 500ms 가드 적용. */
        int64_t since = esp_timer_get_time() - s_lastMoveUs;
        bool autoCall = (s_lastMoveEp == mEndpoint) && (since < WC_STOP_AUTOCALL_GUARD_US);
        if (autoCall) {
            ESP_LOGD(TAG, "[WC] ep=%u idx=%d STOP auto-call 무시 (%lldms after move)",
                     mEndpoint, idx, (long long)(since / 1000));
            return CHIP_NO_ERROR;
        }
        /* oled_action_t: 3 = STOP (somfy_app.c 의 매핑) */
        constexpr uint8_t OA_STOP_LOCAL = 3;
        ESP_LOGI(TAG, "[WC] ep=%u idx=%d STOP → MY 송신", mEndpoint, idx);
        if (idx >= 0) {
            matter_blinds_invoke_action_cb((uint8_t)idx, SOMFY_CMD_MY,
                                           /*pct=*/50, OA_STOP_LOCAL, /*step=*/1);
        }
        return CHIP_NO_ERROR;
    }
};

/* 엔드포인트당 1개 (Delegate::SetEndpoint 가 인스턴스별 mEndpoint 설정) */
static SomfyWCDelegate s_wc_delegates[BLIND_MAX_COUNT];

/* eFuse 기반 기기 고유 커미셔닝 데이터(discriminator/passcode) provider */
static EfuseCommissionableDataProvider g_efuse_comm_provider;

constexpr auto k_timeout_seconds = 300;

#ifdef CONFIG_ENABLE_SET_CERT_DECLARATION_API
extern const uint8_t cd_start[] asm("_binary_certification_declaration_der_start");
extern const uint8_t cd_end[] asm("_binary_certification_declaration_der_end");

const chip::ByteSpan cdSpan(cd_start, static_cast<size_t>(cd_end - cd_start));
#endif // CONFIG_ENABLE_SET_CERT_DECLARATION_API

#if CONFIG_ENABLE_ENCRYPTED_OTA
extern const char decryption_key_start[] asm("_binary_esp_image_encryption_key_pem_start");
extern const char decryption_key_end[] asm("_binary_esp_image_encryption_key_pem_end");

static const char *s_decryption_key = decryption_key_start;
static const uint16_t s_decryption_key_len = decryption_key_end - decryption_key_start;
#endif // CONFIG_ENABLE_ENCRYPTED_OTA

/* ★ Phase 1: WindowCovering 클러스터 서버는 CONFIG_SUPPORT_WINDOW_
 *   COVERING_CLUSTER=y 로 window-covering-server.cpp 가 정식 컴파일됨
 *   (우리 원본 프로젝트와 동일). 별도 stub 불필요. */
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
extern "C" void app_main()
{
#if OLED_ONLY_TEST
    /* ★2026-07-22 OLED 단독 부팅 테스트 — 최상단 단락.
     *  Matter/Thread/BLE/CC1101 RF/PCF8574 버튼/배터리 ADC/진동/절전 등 이후 모든
     *  초기화를 건너뛰고 OLED I2C 만 단독 구동한다(무한 루프, 반환 안 함).
     *  → 다른 기능이 하나도 안 돌므로 OLED 외 나머지 핀 입력은 자동으로 무시됨.
     *  활성화: build.ps1 -OledTest (test/somfy_cases/oled_only_test.c). */
    oled_only_test();   /* 선언: 위 extern "C" 블록 (C 링키지) */
    return;
#endif

    esp_err_t err = ESP_OK;

    /* ═══ RF 안테나 스위치 — **Matter/Thread 라디오가 뜨기 전에** 잡는다 ═══
     *  ★★★2026-09-02 지금까지 이 코드가 아예 없었다. XIAO ESP32C6 는 온보드
     *  FM8625H 로 내장 세라믹 ↔ 외장 u.FL 을 고르는데, 기본이 내장이라
     *  **외장 안테나를 꽂아도 전혀 쓰이지 않았다**(사용자 신고로 발견).
     *  순서·의미는 boards/xiao-c6.h 주석 참조.
     *  ※ 여기(NVS 보다 앞)에 두는 이유: 첫 Thread attach 부터 올바른 안테나로
     *    붙어야 RSSI·재전송이 처음부터 정상이다. */
#if BOARD_HAS_RF_ANT_SW
    {
        const gpio_num_t _en  = (gpio_num_t)BOARD_PIN_RF_SW_EN;
        const gpio_num_t _sel = (gpio_num_t)BOARD_PIN_RF_ANT_SEL;
        gpio_config_t _ac = {
            .pin_bit_mask = (1ULL << _en) | (1ULL << _sel),
            .mode         = GPIO_MODE_OUTPUT,
            .pull_up_en   = GPIO_PULLUP_DISABLE,
            .pull_down_en = GPIO_PULLDOWN_DISABLE,
            .intr_type    = GPIO_INTR_DISABLE,
        };
        gpio_config(&_ac);
        gpio_set_level(_en, 0);                    /* LOW = 스위치 제어 활성 */
        vTaskDelay(pdMS_TO_TICKS(100));            /* Seeed 예제와 동일한 여유 */
        gpio_set_level(_sel, BOARD_RF_EXT_ANT ? 1 : 0);
        /* ★CONFIG_PM_SLP_DISABLE_GPIO=y 라 자동 절전 때 GPIO 가 통째로 꺼진다.
         *  그대로 두면 **수면 구간마다 안테나가 내장으로 되돌아간다**(SED 는 자면서
         *  폴링하므로 치명적). 이 두 핀만 그 기능에서 빼둔다(Kconfig 도움말이
         *  안내하는 방법). */
        gpio_sleep_sel_dis(_en);
        gpio_sleep_sel_dis(_sel);
        ESP_LOGW("MAIN", "[ANT] RF 스위치: EN(IO%d)=LOW, SEL(IO%d)=%s → **%s 안테나**",
                 (int)_en, (int)_sel, BOARD_RF_EXT_ANT ? "HIGH" : "LOW",
                 BOARD_RF_EXT_ANT ? "외장(u.FL)" : "내장(세라믹)");
    }
#endif

    /* Initialize the ESP NVS layer */
    nvs_flash_init();

    /* ★2026-08-11 부팅 단계 기록 시작 — "USB 없이 배터리만 연결하면 부팅 중 멈춘다"
     *  진단용. USB 를 꽂는 순간 전원이 바뀌어 증상이 사라지므로 시리얼 로그를 볼 수
     *  없다 → 전원이 끊겨도 남는 NVS 에 단계를 남기고, 다음 부팅에 읽어 찍는다.
     *  (RTC 메모리는 배터리를 빼면 지워져 쓸 수 없다.) */
    boot_diag_begin();   /* stage 는 begin() 이 APP_MAIN 으로 시작 */

    MEMORY_PROFILER_DUMP_HEAP_STAT("Bootup");

    /* ── WS2812 LED 드라이버는 RMT 채널/인터럽트를 점유해 Somfy RMT 와
     *   충돌("No free interrupt inputs for RMT")한다. 본 제품엔 WS2812 LED
     *   가 없으므로 LED 드라이버 init 을 하지 않는다. 버튼은
     *   app_reset(공장초기화)용으로만 유지. */
    /* ★2026-08-23 공장초기화 버튼(iot_button) 제거 — app_driver.cpp 주석 참조.
     *  20ms 주기 esp_timer 가 상시 돌아 깨어남의 78% 를 차지하고 있었다.
     *  (배터리 오독과의 무관함은 A/B 로 확인 — 같은 주석 참조) */

    /* Create a Matter node and add the mandatory Root Node device type on endpoint 0 */
    node::config_t node_config;

    // node handle can be used to add/modify other endpoints.
    node_t *node = node::create(&node_config, app_attribute_update_cb, app_identification_cb);
    ABORT_APP_ON_FAILURE(node != nullptr, ESP_LOGE(TAG, "Failed to create Matter node"));

    MEMORY_PROFILER_DUMP_HEAP_STAT("node created");

    /* ★ Time Synchronization 클러스터를 Root Node(EP0)에 추가.
     *  esp-matter root_node 기본 구성엔 없으므로 수동 추가. 이러면
     *  SmartThings(커미셔너)가 페어링 시 + 주기적으로 SetUTCTime 명령을
     *  보내고, CHIP TimeSynchronizationCluster → SystemClock SetClock_RealTime
     *  → ESP32 settimeofday() 로 시스템 시각이 설정된다. OLED 시계가
     *  쓰는 time()/localtime() 이 SmartThings 허브 시각과 동기화됨
     *  (인터넷/SNTP 없이도). delegate 불필요(기본 SetUTCTime 처리). */
    {
        endpoint_t *root_ep = endpoint::get(node, 0);
        if (root_ep) {
            cluster::time_synchronization::config_t ts_cfg;
            cluster_t *ts = cluster::time_synchronization::create(
                root_ep, &ts_cfg, CLUSTER_FLAG_SERVER);
            ESP_LOGI(TAG, "Time Synchronization 클러스터 추가 (root EP0) %s",
                     ts ? "OK" : "실패");
        } else {
            ESP_LOGW(TAG, "root endpoint(0) 미발견 — TimeSync 클러스터 skip");
        }
    }

    /* BLIND_MAX_COUNT-endpoint WindowCovering 브리지 구성. init/이벤트/OpenThread/start
     *   는 esp-matter 표준 흐름을 그대로 사용한다. */
    {
        using namespace chip::app::Clusters;
        const uint32_t WC_FEATURES =
            (uint32_t)WindowCovering::Feature::kLift |
            (uint32_t)WindowCovering::Feature::kTilt |
            (uint32_t)WindowCovering::Feature::kPositionAwareLift |
            (uint32_t)WindowCovering::Feature::kPositionAwareTilt;

#if BOARD_MATTER_COMPOSED
        /* ★ composed device — Aggregator/bridged_node 없이 root 아래 WindowCovering
         *  endpoint 를 직접 부착. free 빠듯한 보드(H2)에서 Aggregator endpoint + 블라인드마다의
         *  BridgedDeviceBasicInformation 클러스터를 제거해 RAM 을 아낀다(~수십KB/노드).
         *  단일 기기의 다중 endpoint 로 노출(컨트롤러에서 기기 1개 + endpoint 여러개). */
        for (int i = 0; i < BLIND_MAX_COUNT; i++) {
            window_covering::config_t wc_config;
            wc_config.window_covering.type = 0x00;  // Rollershade
            wc_config.window_covering.feature_flags = WC_FEATURES;
            wc_config.window_covering.features.position_aware_lift.current_position_lift_percent_100ths = nullable<uint16_t>(0);
            wc_config.window_covering.features.position_aware_lift.target_position_lift_percent_100ths  = nullable<uint16_t>(0);
            wc_config.window_covering.features.position_aware_tilt.current_position_tilt_percent_100ths = nullable<uint16_t>(0);
            wc_config.window_covering.features.position_aware_tilt.target_position_tilt_percent_100ths  = nullable<uint16_t>(0);
            wc_config.window_covering.delegate = &s_wc_delegates[i];
            endpoint_t *ep = window_covering::create(node, &wc_config, ENDPOINT_FLAG_NONE, NULL);
            ABORT_APP_ON_FAILURE(ep != nullptr,
                ESP_LOGE(TAG, "Failed to create window_covering %d", i));

            uint16_t wid = endpoint::get_id(ep);
            if (i == 0) light_endpoint_id = wid;
            s_wc_ep_ids[i] = wid;
            s_wc_delegates[i].SetEndpoint(wid);
            ESP_LOGI(TAG, "WindowCovering[%d] ep=%d (composed, root 직속)", i, wid);
        }
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

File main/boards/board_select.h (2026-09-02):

#pragma once
/*
 * boards/board_select.h
 * ──────────────────────────────────────────────────────────
 * 빌드 시점에 -DBOARD_<NAME>=1 매크로로 보드별 핀맵 선택.
 *
 * 사용 (브랜드-SoC 단위 키):
 *   build.ps1 -Board gnpe-c6  → -DBOARD_GNPE_C6=1  (GNPE ESP32-C6-0.42, 검증)
 *   build.ps1 -Board xiao-c6  → -DBOARD_XIAO_C6=1  (Seeed XIAO ESP32-C6)
 *   build.ps1 -Board esp32-h2 → -DBOARD_ESP32_H2=1
 *   (구 -Board esp32-c6 = gnpe-c6 별칭 — 역호환)
 *
 * ★ 같은 SoC(esp32c6)라도 브랜드(GNPE/XIAO)마다 핀 배열이 다르므로 board 파일
 *   을 브랜드별로 분리한다. OTA 구분도 chip-ID 가 같아(esp32c6) 안 되므로
 *   브랜드별 Product ID 로만 구분 — 각 board 의 PID 가 달라야 한다.
 *
 * 새 보드 추가:
 *   1. boards/<brand>-<soc>.h 작성 (BOARD_PIN_* 모두 정의)
 *   2. 아래 분기에 #elif 추가
 *   3. build.ps1 의 $BoardMap (idf target/sdkconfig/PID) 갱신
 *   4. (선택) sdkconfig.defaults.<name> 추가 (브랜드별 PID 등)
 * ──────────────────────────────────────────────────────────
 */

#if defined(BOARD_GNPE_C6) || defined(BOARD_ESP32_C6)
   /* GNPE ESP32-C6-0.42 (현 검증 보드). BOARD_ESP32_C6 은 구 키 backward 별칭. */
#  include "boards/gnpe-c6.h"
#elif defined(BOARD_XIAO_C6_TEST)
   /* ★2026-08-16 XIAO C6 테스트 보드(COM6) — xiao-c6.h 를 상속해 차이만 덮는다.
    *  ※BOARD_XIAO_C6 보다 **먼저** 검사한다. 보드 매크로가 두 개 다 정의되는
    *    경우가 생겨도 테스트 프로파일이 이기도록. */
#  include "boards/xiao-c6-test.h"
#elif defined(BOARD_XIAO_C6)
#  include "boards/xiao-c6.h"
#elif defined(BOARD_ESP32_H2)
#  include "boards/esp32-h2.h"
#else
#  error "No board selected. Build with -DBOARD_ESP32_C6=1 (or another supported board). \
See main/boards/ for available boards."
#endif

/* ── OLED 규격 기본값 (보드가 BOARD_OLED_* 를 안 주면 GNPE 0.42" 72×40 가정) ──
 *   보드별 디스플레이가 다르므로 boards/<board>.h 에서 정의하는 게 원칙.
 *   여기 fallback 은 구 보드 파일 호환용 안전망. */
#ifndef BOARD_OLED_WIDTH
#  define BOARD_OLED_WIDTH       72
#endif
#ifndef BOARD_OLED_HEIGHT
#  define BOARD_OLED_HEIGHT      40
#endif
#ifndef BOARD_OLED_COL_OFFSET
#  define BOARD_OLED_COL_OFFSET  28
#endif
#ifndef BOARD_OLED_ROTATE_180
#  define BOARD_OLED_ROTATE_180   1
#endif
#ifndef BOARD_OLED_FIXUP_72X40
#  define BOARD_OLED_FIXUP_72X40  1
#endif
#ifndef BOARD_OLED_FLIP_X
#  define BOARD_OLED_FLIP_X       0   /* 좌우(가로) 반전 — 기본 꺼짐(역호환) */
#endif
#ifndef BOARD_OLED_ROTATE_90
#  define BOARD_OLED_ROTATE_90    0   /* 0 / 90(시계) / 270(반시계) — 기본 회전 없음 */
#endif
#ifndef BOARD_OLED_ADDR
#  define BOARD_OLED_ADDR        0x3C
#endif

/* ── OLED 렌더러는 "해상도"로 자동 선택된다 (보드 무관) ───────────────────
 *   oled_ui.c 는 위 BOARD_OLED_WIDTH×HEIGHT 값만 보고 렌더러를 고른다
 *   (oled_ui.h 의 OLED_RENDER_* 매크로). 즉 디스플레이는 보드마다 자유롭게
 *   교체 가능하며, 보드는 패널 규격(이 6개 매크로)만 선언하면 된다.
 *
 *     128×64 (가로)  → 풀스크린 네이티브 렌더러 (고딕 6×9 + 7세그, 가로 배치)
 *     64×128 (세로)  → 풀스크린 네이티브 렌더러 (고딕 6×9 + 7세그, 세로 적층)
 *     그 외          → 72×40 논리 캔버스 렌더러 (어떤 패널에도 중앙 배치/블록 스케일)
 *
 *   예1) GNPE 에 0.96" 128×64 패널 → gnpe-c6.h 의 BOARD_OLED_* 를
 *        128×64/COL_OFFSET=0/FIXUP=0 으로 (코드 수정 불필요, CONFIG_OFFSETX=0).
 *   예2) 어느 보드든 64×128 세로 패널(SH1107 등) → BOARD_OLED_* 를
 *        64×128 으로 선언하면 세로 레이아웃 렌더러가 자동 적용된다. */

/* ── I2C 버스 공유 플래그 ──────────────────────────────────────────────
 *   0 (기본): OLED=하드웨어 I2C, PCF8574=소프트웨어 비트뱅 (서로 다른 핀).
 *   1       : OLED 와 PCF8574 가 하드웨어 I2C 한 버스를 공유(SDA/SCL 동일 핀).
 *             LP_I2C 가 없거나 핀이 부족한 보드(ESP32-H2 등)에서 사용.
 *             이 경우 BOARD_PIN_OLED_SDA==BOARD_PIN_PCF_SDA,
 *                      BOARD_PIN_OLED_SCL==BOARD_PIN_PCF_SCL 이어야 한다. */
#ifndef BOARD_I2C_SHARED
#  define BOARD_I2C_SHARED       0
#endif

#if BOARD_I2C_SHARED
#  if (BOARD_PIN_OLED_SDA != BOARD_PIN_PCF_SDA) || (BOARD_PIN_OLED_SCL != BOARD_PIN_PCF_SCL)
#    error "BOARD_I2C_SHARED=1 인데 OLED 와 PCF8574 의 SDA/SCL 핀이 다릅니다 (같은 버스여야 함)."
#  endif
#endif

/* ── LP_I2C → 공유 HW I2C 런타임 자동 폴백 (XIAO 등) ──────────────────────
 *   0 (기본): 폴백 없음 — 위 BOARD_I2C_SHARED 단일 경로만 사용.
 *   1       : 부팅 시 LP_I2C 전용핀(BOARD_PIN_PCF_LP_SDA/SCL) 비트뱅으로 PCF8574
 *             프로브 → 응답 없으면 공유 HW I2C(OLED 버스)로 자동 전환.
 *             → 같은 펌웨어가 "뒷면 LP_I2C 배선" / "앞면 공유 I2C 배선" 모두 지원.
 *   조건: BOARD_I2C_SHARED=1(폴백 대상) + BOARD_PIN_PCF_LP_SDA/SCL 정의 필수. */
#ifndef BOARD_I2C_LP_FALLBACK
#  define BOARD_I2C_LP_FALLBACK  0
#endif

/* ── OLED 를 소프트웨어 비트뱅 I2C 로 구동 (2026-07-23) ─────────────────────
 *   0 (기본): ESP32 HW I2C 페리페럴 사용(기존 동작).
 *   1       : 순수 GPIO 비트뱅으로 OLED 전송. HW I2C 버스를 만들지 않는다.
 *   왜: xiao-c6(h4)에서 **HW I2C0 가 "bus busy" 로 고착**되는 현상이 실측 재현됨
 *       (라인은 idle 1/1 인데 clear bus failed / reset hardware failed, 버스 재생성도 무효).
 *       같은 순간에도 비트뱅은 0x3C ACK 를 받아낸다 → 페리페럴을 통째로 우회한다.
 *   주의: PCF8574 를 OLED 와 **공유 HW I2C**로 쓰는 보드(BOARD_I2C_SHARED 경로)는
 *       버스 핸들이 없어지므로 함께 쓰지 말 것(현 xiao-c6 는 PCF 가 LP 비트뱅이라 무관). */
#ifndef BOARD_OLED_BITBANG
#  define BOARD_OLED_BITBANG     0
#endif
#if BOARD_I2C_LP_FALLBACK
#  if !BOARD_I2C_SHARED || !defined(BOARD_PIN_PCF_LP_SDA) || !defined(BOARD_PIN_PCF_LP_SCL)
#    error "BOARD_I2C_LP_FALLBACK=1 requires BOARD_I2C_SHARED=1 and BOARD_PIN_PCF_LP_SDA/SCL."
#  endif
#endif
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

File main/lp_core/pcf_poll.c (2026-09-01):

/*
 * pcf_poll.c — LP 코어 프로그램: PCF8574 폴링 + 로터리 쿼드러처 디코딩
 * ═════════════════════════════════════════════════════════════════════
 * 이 파일은 **LP 코어(ULP-RISC-V)에서 실행**된다. HP(메인 CPU)와는 공유 RAM
 * 변수로만 통신한다. HP 쪽에서는 `ulp_<변수명>` 으로 접근한다.
 *
 * 왜 존재하나 (③)
 * ----------------
 * 실측 6.64시간 평균 57mA / 사용시간 12.3h. 원인은 Matter 가 아니라 HP 가
 * **10ms 마다 깨어나 PCF8574 를 비트뱅 I2C 로 읽는 것**이었다(초당 100회).
 * PCF 의 `~INT` 로 이벤트 구동하려던 시도(②)는 실측으로 불가 판정됐다
 * (버튼을 눌러도 선이 안 움직임 — 표본 290,023 / 전이 0회).
 * → 남은 방법은 **폴링 주체를 LP 코어로 옮기는 것**뿐이다.
 *
 * ★로터리를 여기서 디코딩하는 이유 (②가 깨진 바로 그 지점)
 * -----------------------------------------------------------
 * 디텐트 1개는 A/B 전이 2회가 **수 ms 안에** 끝난다. LP 가 "변화 있음"만 알리고
 * HP 가 깨어나서 읽으면 그 전이는 이미 지나가 **방향을 알 수 없다**.
 * 그래서 쿼드러처 누산을 여기서 끝내고 **디텐트 개수(부호 포함)** 만 넘긴다.
 * 버튼은 눌림이 100ms 이상 유지되므로 HP 가 나중에 읽어도 안전하다.
 *
 * 통신 규약 (공유 RAM)
 * --------------------
 *   pcf_state   최신 PCF 1바이트 원본 (HP 가 버튼 디바운스에 그대로 사용)
 *   rot_delta   누적 디텐트. HP 가 읽고 **뺀 만큼 차감**한다(소비형).
 *   seq         상태가 바뀔 때마다 증가 — HP 는 이 값으로 변화 유무를 판단
 *   poll_cnt    폴링 누적(살아있음 확인)
 *   i2c_err     I2C 실패 누적 — 늘어나면 LP 경로를 접고 HP 폴링으로 되돌릴 근거
 *   enabled     HP 가 0 으로 두면 LP 는 I2C 를 건드리지 않는다(HP 가 버스를 쓸 때)
 */

#include <stdint.h>
#include "ulp_lp_core_utils.h"
#include "ulp_lp_core_i2c.h"
#include "pcf_lp_config.h"   /* ★LP·HP 공용 — 읽기 폭/비트 위치 */

/* C6 는 LP_I2C 포트가 하나뿐(SOC_LP_I2C_NUM=1) */
#define PCF_I2C_PORT   LP_I2C_NUM_0
#define PCF_I2C_ADDR   0x20        /* PCF8574/8575 (A0~A2 = GND) — 부팅 로그와 동일 */

#define I2C_TIMEOUT_CYCLES 5000    /* 예제와 동일. 무한 대기 금지(멈추면 복구 불가) */
/* 폴 주기는 공유 헤더로 옮겼다 — HP 가 LP 타이머 주기로 같은 값을 써야 한다. */
#define POLL_US LP_POLL_US

/* ── HP 와 공유하는 변수 (HP 에서는 ulp_* 로 접근) ─────────────────────── */
volatile uint32_t pcf_state  = 0xFFFFFFFFu; /* 최신 원본(8/16비트). 0xFFFFFFFF = 아직 읽기 전 */
volatile int32_t  rot_delta  = 0;        /* 누적 디텐트(+CW/-CCW). HP 가 차감 */
volatile uint32_t seq        = 0;        /* 변화 카운터 */
/* ★★★2026-08-23 **눌림 래치** — HP 폴 주기를 늘려도 짧은 누름을 잃지 않게 한다.
 *
 *  왜 필요한가: HP 는 25ms 마다 `pcf_state`(=현재 상태)를 읽는다. 폴과 폴 사이에
 *  눌렀다 뗀 누름은 **통째로 사라진다**. 그래서 주기를 못 늘렸고, 그게 전체
 *  깨어남의 53%(46.8회/초)를 차지한다.
 *  → LP 가 2ms 마다 보면서 **한 번이라도 눌렸던 비트를 OR 로 모아 둔다**.
 *    HP 는 "지금 눌림 OR 그동안 눌렸음" 으로 판정하므로 누락이 없다.
 *
 *  버튼은 active-low(풀업, 눌림=0)라 `~rx` 의 1 비트가 '눌렸음' 이다.
 *  소비 규약은 rot_delta 와 동일하게 **HP 가 본 것만 차감**한다:
 *      uint32_t d = ulp_press_latch;  ...사용...  ulp_press_latch &= ~d;
 *  (HP 가 통째로 0 을 쓰면, 읽기와 쓰기 사이에 LP 가 OR 한 비트를 잃는다.) */
volatile uint32_t press_latch = 0;
volatile uint32_t poll_cnt   = 0;        /* 폴링 누적(생존 확인) */
volatile uint32_t i2c_err    = 0;        /* I2C 실패 누적 */
volatile uint32_t enabled    = 1;        /* HP 가 0 으로 내리면 I2C 정지 */

/* ── 쿼드러처 LUT — button_handler.c 의 kQuad 와 **같은 표** ────────────
 *  인덱스 = (이전 AB << 2) | 현재 AB. ±1 이 모여 ±2 가 되면 1 디텐트.
 *  바운스(왕복)는 +1/−1 로 상쇄돼 자동 제거된다. */
static const int8_t kQuad[16] = {
    0, +1, -1,  0,
   -1,  0,  0, +1,
   +1,  0,  0, -1,
    0, -1, +1,  0,
};

/* PCF8574 비트 배치 — button_handler.h 와 동일해야 한다.
 * 여기서 헤더를 include 하지 않는 이유: LP 코어 툴체인은 HP 쪽 헤더 체인
 * (FreeRTOS/esp_log 등)을 못 따라간다. 값만 최소로 복제하고, 어긋나면
 * 로터리가 안 도는 형태로 즉시 드러난다. */
#define BIT_ROT_A   LP_BIT_ROT_A
#define BIT_ROT_B   LP_BIT_ROT_B

/* ★★★2026-09-01 상태를 **파일 스코프**로 올렸다 — halt/타이머 방식의 전제다.
 *  main() 이 폴 1회마다 새로 호출되므로 자동 변수로 두면 매번 초기화돼
 *  쿼드러처 누산(accum/prev_ab)·변화 감지(last)·2연속 래치(prev_low)가 전부 깨진다.
 *  파일 스코프 static 은 LP RAM 에 남아 폴 사이에 보존된다. */
static uint8_t  prev_ab  = 0x03;         /* 디텐트 기본 위치(11) */
static int8_t   accum    = 0;
static uint32_t last     = 0xFFFFFFFFu;  /* '아직 안 읽음' 표식 — 16비트 값과 겹치면 안 된다 */
static uint32_t prev_low = 0;            /* 2연속 눌림 판정용 직전 표본 */
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

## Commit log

2026-06-01 chore: initial empty commit
    HEAD 이 unborn 이면 esp_insights git_describe 가 reconfigure 에서
    실패해 빌드가 안 된다. 빈 커밋으로 HEAD 를 살려 빌드를
    푸는 최소 커밋 (내용 커밋은 추후 별도).
2026-08-06 feat: Somfy RTS 블라인드 컨트롤러 펌웨어 초기 임포트
    ESP32-C6/H2 기반 Somfy RTS 블라인드 컨트롤러 (Matter/Thread + CC1101 RF).
    주요 구성:
    - main/: 펌웨어 소스 (Matter 노드/WindowCovering, Somfy RTS 프로토콜,
    CC1101 드라이버, OLED UI, PCF8574 버튼/로터리, 블라인드 관리)
    - main/boards/: 보드별 핀맵 (xiao-c6 / gnpe-c6 / esp32-h2)
    - test/: 테스트 하네스 (RF 셀프테스트/온에어/디코더, OLED 단독 부팅 테스트)
    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
    [E07-400MM10S.PcbLib, E07-400MM10S.step, E07-M1101D.PcbLib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]
2026-08-06 feat(test): OLED 단독테스트에 교차연결·버스복구 진단 추가
    회로도(somfy_blinds_h4) 분석에서 신 PCB 의 I2C SPDT 스위치(SDA1/SCL1)를 발견:
    C = I2C(GPIO22/23, OLED) ─ B = PCF8575 / A = LP_I2C(GPIO6/7)
    스위치가 A 위치면 GPIO22↔GPIO6, GPIO23↔GPIO7 이 단락되어 버튼용 LP 비트뱅이
    OLED 버스를 깨뜨린다. 이를 실측으로 확정하기 위해 진단 2종 추가:
    - [XCONN] 교차연결 검사: LP(6/7)를 LOW 로 구동하고 OLED 핀(22/23) 레벨 관찰.
    따라 내려가면 스위치 A위치 단락, 독립이면 정상.
    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
2026-08-09 fix(oled): 화면 멈춤 대응 — 비트뱅 I2C 전환 + RF 송신 중 버스 차단
    실기(COM7=xiao-c6 h4)에서 "화면이 마지막 프레임에 멈추는" 현상을 추적해
    원인을 두 층으로 분리하고 각각 대응했다.
    1) ESP32 HW I2C0 페리페럴 고착
    증상: 라인은 idle(1/1)인데 `i2c.master: clear bus failed` +
    `s_i2c_transaction_start: reset hardware failed` → 부팅 4.5초 만에 붕괴.
    버스 del→재생성으로도 안 풀림. 같은 순간 순수 GPIO 비트뱅은 0x3C ACK 정상.
    → BOARD_OLED_BITBANG=1 (xiao-c6): OLED 전송을 비트뱅으로 전환하고
    HW I2C 버스를 아예 생성하지 않는다. 전송 3곳·probe·패널in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
    [board_select.h, oled_ui.c, oled_ui.h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]
2026-08-09 feat(oled): 화면보호기 제거, 화면 OFF 시간을 설정값으로 분리
    사용자 요청: "화면보호기 기능 완전 삭제, 화면 꺼지는 시간을 설정값으로".
    화면보호기 삭제 (코드 제거)
    - 유휴 정책의 2단계(화면보호기 애니메이션) 분기를 통째로 삭제.
    이제 1단계 정상화면 → (유휴 타임아웃) → 패널 OFF 2단계만 남는다.
    - 관련 잔재 제거: SAVER_ANIM_MS / SCREENSAVER_TIMEOUT_MS / SLEEP_TIMEOUT_MS /
    SCREENSAVER_DISABLE 상수, s_saver_anim 변수, 진동 분기의 애니 종료 블록.
    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
2026-08-09 perf(oled): 비트뱅 I2C를 GPIO 레지스터 직접 접근으로 전환 + 400kHz
    증상: 비트뱅 전환 후 화면 갱신이 느려 애니메이션이 눈에 띄게 굼떴다.
    400kHz 로 올려봤더니 화면에 랜덤 점이 가득 찍혔다(전송 데이터 손상).
    원인 1 — HAL 호출 오버헤드
    비트마다 gpio_set_direction() 을 불렀다. 호출 비용이 크고 불규칙해
    (a) 실효 속도가 공칭의 몇 분의 1 (b) 파형 지터로 400kHz 에서 데이터 깨짐.
    → GPIO 레지스터 직접 접근으로 교체(REG_WRITE OUT_W1TS/W1TC, REG_READ IN).
    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
2026-08-09 chore(diag): OLED 멈춤 원인 격리용 임시 차단 플래그 추가
    배경: 비트뱅 400kHz 전환 후에도 OLED 가 사용 중/부팅 중 멈추는 문제가 남았다.
    사용자 지적 — "충전률 측정과 버튼 RF 송신 부분을 변경하면서 망가진 것 같다".
    somfy_app.c 에 이분 탐색용 임시 플래그 2개를 추가했다(코드는 삭제하지 않고 #if 로만 차단).
    TEMP_NO_CHARGE : 배터리 ADC init + 충전 감지 비활성(charging=false 고정)
    TEMP_NO_BTN_RF : 버튼으로 발생하는 RF 송신 job 투입 차단(Matter 경로는 유지)
    격리 경과
    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
2026-08-09 chore(diag): OLED 비트뱅 전송 안정성 계측 추가
    목적: "충전측정을 끄면 정말 안 멈추는가"를 숫자로 검증하고, 다시 멈출 때
    언제부터 나빠졌는지 시점을 특정하기 위한 계측.
    추가한 것
    - oled_ui.c: 비트뱅 전송 시도/실패 누적 카운터(g_bbo_tx_cnt / g_bbo_fail_cnt),
    실패 시각(g_bbo_last_fail_us), 검출상태 미러(g_oled_present_mon).
    실패 시 [BBFAIL] 로그 — 20회마다 1줄만 찍어 로그 폭주를 막는다.
    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
2026-08-10 perf(oled): dirty-page 전송 감축 + RF 송신 중 화면차단 해제
    1) dirty-page 전송 감축
    계측 결과 화면 전체를 초당 ~11장 재전송해 **초당 약 450건**의 I2C 트랜잭션이
    발생했다(전송 1건마다 고착 기회). 실제로 바뀌는 건 시계 등 일부뿐인데 전량을
    매번 보내고 있었다.
    → 마지막으로 성공 전송한 내용을 s_shadow 에 보관하고, 페이지 내용이 바뀐 경우에만
    전송한다. 전송 실패 시 shadow 를 갱신하지 않아 다음 주기에 자동 재시도되고,
    검출 실패/재검출 시에는 shadow 를 무효화해 전량 재전송한다.
    ※flush 경로가 5갈래(rot/flip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
    [oled_ui.c]
2026-08-10 feat(btn): RF 버튼 조작 중 채널변경(SELECT·좌·우) 무시
    문제
    - 상/하, 상/정지, 하/정지 를 **동시에** 누를 때 손가락이 스치며 좌/우 가 같이 눌려
    채널이 바뀌어 버렸다. 동시 누름은 완전히 같은 순간이 아니라 약간의 텀이 있다.
    - 상/하/정지/PROG 로 RF 를 쏘는 중에 채널이 바뀌면 엉뚱한 블라인드로 명령이 나간다.
    조치 — 채널변경 잠금(_ch_locked)
    - 잠금 대상(채널변경 계열): SELECT / LEFT / RIGHT.
    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
2026-08-10 feat(oled): 화면보호기 코드 완전 삭제
    증상: 앞서 화면보호기를 제거했다고 했는데도 화면보호기 화면이 계속 나타났다.
    원인 — 화면보호기가 **두 곳**에 있었다
    (1) somfy_app.c 유휴 정책의 2단계(애니메이션) — 커밋 d9a71d1 에서 제거했으나
    (2) oled_ui.c 가 **자체 유휴 타이머**로 2분 뒤 OLED_STATE_SCREENSAVER 로 전환
    (`if (idle_ms >= OLED_SCREENSAVER_IDLE_MS) ctx->state = OLED_STATE_SCREENSAVER;`)
    → (2)를 못 보고 "제거 완료"라고 보고했던 것이 잘못. 이번에 (2)까지 삭제했다.
    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
2026-08-10 fix(oled): 화면이 저절로 켜진 뒤 다시 꺼지지 않는 문제
    증상: 화면이 꺼진 뒤 얼마 지나면 저절로 켜지고, 그 뒤로는 영영 꺼지지 않는다.
    버튼을 누르거나 진동이 발생하면 그때부터는 10초 뒤 정상적으로 꺼진다.
    원인: 유휴 정책의 inhibit 조건에 **스택이 자동으로 진입하는 상태**가 들어 있었다.
    bool inhibit = _in_setup_mode() ||
    s_ui.state == OLED_STATE_CHARGING ||
    s_ui.state == OLED_STATE_PAIRING ||
    s_ui.state == OLED_STATE_THREAD_PROV;
    PAIRING/THREAD_PROV 는 Matter/Thread 스택이 재광고·재부착 등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
2026-08-10 feat(btn): 채널변경 잠금을 애니메이션 종료까지 확장 + 진동 stuck 판별(미작동)
    1) 채널변경 잠금 확장 — 동작함
    요청: "버튼을 눌러 애니메이션이 끝날 때까지 채널 변경이 되지 않도록".
    _ch_locked() 에 `s_ui.state == OLED_STATE_ACTION || s_ui.action_active` 조건 추가.
    버튼을 떼도 동작 애니메이션이 재생되는 동안에는 SELECT·좌·우를 무시한다.
    (기존 조건: RF 버튼 홀드 중 + 마지막 눌림 후 CFG_CH_LOCK_MS 700ms 여운)
    2) 진동센서 stuck 판별 — ★추가했으나 **발동하지 않음(미해결)**
    증상: COM7 화면이 유휴 10초가 지나도 꺼지지 않는다.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
    [button_handler.c]
2026-08-10 fix(oled): 비트뱅 전역을 가드 밖으로 이동(H2 빌드 복구) + 문서 갱신
    빌드 복구 — ESP32-H2(BOARD_OLED_BITBANG=0)에서만 터지던 이식성 버그
    계측 코드를 추가하면서 **선언은 `#if BOARD_OLED_BITBANG` 안, 사용은 가드 밖**에
    두었다. xiao-c6(=1)에서는 드러나지 않고 H2(=0)에서만 실패했다.
    g_oled_present_mon → 컴파일 에러 (undeclared)
    g_bbo_tx_cnt / g_bbo_fail_cnt → 링크 에러 (undefined reference)
    세 전역 모두 가드 밖으로 옮기고 재발 방지 주석을 남겼다.
    ※한 번은 빌드 실패를 확인하지 않고 "플래시 OK"로 보고했다 — 이후 플래시 결과는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
    [oled_ui.c]
2026-08-10 docs: OLED 변경사항을 doc/·sim/ 에 반영
    doc/CHECKLIST.md
    - 삭제된 화면보호기 항목 2줄(OLED_SCREENSAVER_IDLE_MS, _render_screensaver)을
    현재 구현으로 교체. 이 상수/함수는 실제로 코드에서 제거됐다(커밋 b2840a2).
    - 추가: 유휴 후 패널 OFF(CFG_SCREEN_OFF_SEC), 버튼·진동 복귀, OLED 비트뱅 I2C,
    dirty-page 감축, 채널변경 잠금, [OLEDMON]/[BBFAIL] 계측.
    - 충전률 측정은 ⚠ 로 표시 — TEMP_NO_CHARGE=1 로 임시 비활성 상태임을 명시.
    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
2026-08-10 docs: 다음 세션용 인수인계 문서(HANDOFF.md) 추가
    새 세션에서 "HANDOFF.md 읽고 이어서 작업해줘" 한 줄로 컨텍스트를 넘기기 위한 문서.
    담은 내용
    - **최우선: 충전률 측정 재활성** — 확정된 원인(adc_oneshot_read 가 portENTER_CRITICAL 로
    인터럽트를 끈 채 8회 연속 → 비트뱅 전송 파괴), 실기 이분 탐색 결과표,
    ★뮤텍스가 못 덮는 전송 지점 4곳(oled_ui.c:204 _oled_send_cmds / :192 _bbo_probe 가 무방비),
    수정안 4단계와 재귀 락 설계 판단(_fb_flush 바깥 락 제거 후 _bbo_write 단위 잠금 권장).
    - 남은 과제 5건: 진동센서 오검출(stuck 판별 미작동, 먼저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
2026-08-10 fix(oled/bat): OLED 전송 직렬화 구멍 차단 → 충전측정 재활성 + 배터리 % 표시·채널잠금 보완
    ## 1) OLED 전송 직렬화 (oled_ui.c) — 충전측정 재활성의 전제
    충전측정을 켜면 몇 분 내 OLED 가 고착되던 진짜 원인은 "ADC 가 인터럽트를 끈다"가
    아니라 **락이 전송 경로를 다 덮지 못한 것**이었다.
    우선순위가 btn_handler 10 > somfy_app 4 > oled_ui 3 이라 somfy_app 이 oled_ui 를
    **선점**한다. 비트뱅은 CPU 가 곧 클럭이라 선점당한 전송은 SCL/SDA 가 중간 상태로
    수백 us 멈춰 SSD1306 상태머신이 고착된다(한 번 고착되면 저절로 안 풀리는 래치).
    그런데 oled_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
    [adc_oled_mutex_sim.py, bat_pct_display_sim.py, oled_ui.c]
2026-08-11 fix(bat/boot): 배터리 단독 부팅 멈춤 해결 + % 표시 평활 + 화면OFF 전원별 분리
    ## 1) USB 없이 배터리만 연결하면 부팅 중 멈춤 (app_main.cpp)
    증상: USB 를 빼고 배터리만 연결하면 부팅 화면에서 멈추고 40초~1분마다 재부팅.
    USB 를 꽂으면 정상이라 시리얼 로그를 볼 수 없었다.
    원인: esp_matter::console::init() 이 CHIP shell 을 **우선순위 5** 태스크로 띄운다
    (somfy_app=4, oled_ui=3 보다 높다). 프롬프트 출력이
    esp_rom_usb_serial_putc → usb_serial_device_tx_flush() 로 USB 호스트를
    기다리는데, 호스트가 없으면 이 대기가 길어져 prio 5 가 아래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
    [app_main.cpp, bat_pct_smooth_sim.py, oled_ui.c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]
2026-08-11 fix(bat): 만충 4128mV=100% 보정 + 브라운아웃 원복 + 진단로그 60초
    ## 1) 만충 전압 보정 (somfy_app.c) — 사용자 요청
    증상: 충전이 끝났는데 % 가 93~94% 에서 멈춘다.
    원인: 실기 만충 실측이 **4,128~4,132 mV** 로 이론값 4,200 mV 보다 낮다
    (분압 저항 오차 + ADC 캘리브레이션 오차, 약 1.7%).
    [BAT?] 로그로 확인: raw=2061 vadc=2065mV -> vbat=4130mV 가 100초간 ±2mV.
    즉 값이 고정된 게 아니라 **전압이 진짜 평평**했던 것(측정 건너뜀 0회).
    조치: BAT_FULL_MV(기본 4128) 도입. 곡선 **상단 3개 앵커만** 원래 모양을 유지한 채
    [3980..4200] → [3980..BAT_FU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
    [bat_pct_display_sim.py, bat_pct_smooth_sim.py]
2026-08-11 feat(power): Thread MTD/SED(7초)+PM+무선 게이팅으로 배터리 절약 + 방전기록 NVS
    ## A) Thread MTD/SED + Matter ICD (폴링 7초)
    FTD 는 다른 노드를 중계해야 해서 802.15.4 수신부를 끌 수 없다(~70mA).
    리모컨은 중계가 필요 없으므로 MTD + ICD 서버로 바꿔 Sleepy End Device 로 만든다.
    CONFIG_OPENTHREAD_MTD / ENABLE_ICD_SERVER / ICD_SLOW_POLL_INTERVAL_MS=7000
    ★ENABLE_ICD_SERVER 만 켜면 링크가 깨진다 —
    undefined reference: MatterIcdManagementPluginServerInitCallback.
    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
2026-08-11 perf(power): 화면 OFF 시 깨어남 빈도 46 → 9회/초 (light sleep 실효화)
    ## 문제 — light sleep 을 켜도 잘 시간이 없다
    전체 코드를 훑어 화면 OFF 상태에서 CPU 를 깨우는 주기를 집계했다:
    btn_handler 30ms 33.3 회/초 ← 지배적
    somfy_app 100ms 10.0 회/초
    oled_ui 500ms 2.0 회/초
    time_update 1000ms 1.0 회/초
    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
2026-08-11 revert(power): 버튼·메인루프 폴링 지연 되돌림 — 깨우기 경로를 늦추면 안 된다
    직전 커밋(ca30c8f)에서 절전을 위해 화면 OFF 시 폴링을 늦췄는데 **사용성을 깨뜨렸다**.
    사용자 신고: "버튼을 몇 번 눌러야 화면이 켜진다", "진동센서는 거의 작동하지 않는다".
    ## 왜 깨졌나
    · btn_handler 30 → 150ms
    버튼은 PCF8574 뒤에 있어 I2C 폴링으로만 읽는다. 150ms 면 짧은 탭이 두 폴 사이에
    통째로 들어가 놓치고, 잡아도 반응이 150ms 늦는다.
    진동은 더 심각하다 — 진동 스위치는 **수십 ms 짜리 짧은 펄스**라 150ms 간격으로는
    대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
    [button_handler.c]
2026-08-11 refactor(btn): 진동 ISR → 태스크 즉시 통지 (폴링 주기와 검출 지연 분리)
    저전력 입력 검출의 1단계. **동작·응답성은 지금과 동일**하고, 검출 지연을 폴링
    주기에서 떼어내 나중에 유휴 폴링을 늦출 수 있게 하는 준비다.
    · _vibe_isr_handler 가 자기 인터럽트를 끈 뒤 vTaskNotifyGiveFromISR 로 btn_task 를
    즉시 깨운다 → duty-cycle 창 측정을 곧바로 시작.
    · btn_task 의 vTaskDelay(10ms) → ulTaskNotifyTake(pdTRUE, 10ms).
    타임아웃이 10ms 그대로라 현재 거동은 이전과 같다.
    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
2026-08-11 fix(bat): ADC1 충돌 직렬화 + % 숨김에 상한 45초
    ## 1) BAT_ADC ↔ PCF 비트뱅 ADC1 충돌 (실사용 신고)
    증상: 좌/우 버튼 연타 중 38→39→**40%** 로 **올라갔다**(부하가 걸리면 내려가야 하므로
    물리적으로 불가능). 재부팅 후엔 44→45→**37%** 로 널뛰었다.
    원인: BAT_ADC(GPIO1)=ADC1_CH1, PCF 비트뱅(GPIO6)=ADC1_CH6 으로 **같은 ADC1 유닛**이라
    버튼 비트뱅이 GP6 을 토글하면 GP1 변환이 교란된다. 이 직렬화가 필요하다는 건 코드
    주석에 이미 있었는데 **실패 경로가 빠져 있었다** — 버튼 뮤텍스를 못 잡아도(_locked=false)
    ADC 를 그냥 읽었다(OLED 락만 검사).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
2026-08-12 fix(bat/ui): 방전 중 % 상승 차단 + 설정 버튼 MY↔SETUP 교환 + 부팅 버전 표시
    배터리 % 가 방전 중에 68>69>70>71 로 올라가던 문제.
    NVS 방전기록(세션 #16, 290건) 분석 결과 원본 전압이 두 무리로 갈라진다:
    3902~3924(평균 3913) / 3932~3958(평균 3944), 간격 31mV, 중간값 거의 없음.
    USB 연결 중엔 같은 기기가 ±4mV(ADC 2카운트)라 배터리 구동일 때만 갈라진다.
    중앙값-9 가 어느 무리에 다수결이 걸리느냐로 31mV(≈5%p)씩 튀고, EMA 가 그
    계단을 부드럽게 따라가 '단조 상승' 으로 보였다.
    - (C) USB→배터리 전환 시 평활 초기화 + 세션 기준점 지연
    분리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
    [bat_pct_monotone_sim.py, button_handler.c, oled_ui.c]
2026-08-12 feat(ui/bat): 부팅 진행 화면 + ADC 절사평균 + 방전 전류 수식 10배 오류 수정
    ■ 부팅 진행 화면 (사용자 요청)
    미페어링 부팅은 앱 태스크(OLED 갱신·버튼 폴링)가 커미셔닝 타이밍 보호를 위해
    약 17초 뒤에 시작된다(_deferred_task_starter: 선대기 5s + 페어링 감시 12s).
    그동안 메인 화면을 1회 그려놓고 방치해서, 화면은 멀쩡한데 버튼이 안 먹는
    "먹통" 으로 보였다(실측 16.5초).
    - oled_ui_show_booting(ctx, pct): 로고+버전+진행 바를 직접 렌더(_ui_task 가 아직
    없어 상태만 바꿔선 아무도 안 그린다). 0.5초 주기 — 보호 대상인 20fps 보다 한참
    낮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
    [bat_adc_trim_sim.py, oled_ui.c, oled_ui.h]
2026-08-12 fix(matter/icd): SmartThings offline 원인 — ICD IdleModeDuration 2초 → 30초
    증상: Matter 페어링은 완료됐는데 SmartThings 에서 블라인드가 offline 이고
    복구되지 않는다.
    진단(실기 로그): **네트워크는 정상이었다.**
    Mle: Role detached -> child ← Thread 부착됨
    CASE Session established to peer: <E7B9CA2F8BFF99F9, 1>
    chip[DMG]: Final negotiated min/max parameters: Min = 0s, Max = 2s
    → 이후 IM:ReportData 를 2.02초마다 송신, 허브가 매번 status 0x00 로 응답
    원인: CHIP 은 구독 최대주기를 **IdleModeDuration 으로 협상**한다
    (ReadHandler.cpp: "synchronize the subscription report interval with the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
    [bat_pct_display_sim.py, bat_pct_monotone_sim.py, bat_pct_smooth_sim.py]
2026-08-13 feat(power/diag): FreeRTOS tick 1000Hz + 진동 NVS 기록 / `~INT` 인터럽트 불가 확정
    ■ 절전 ① — FreeRTOS tick 100 → 1000 Hz
    실측 6.64시간(세션 #22) 평균 57mA, 사용시간 12.3h. 원인은 Matter 가 아니라
    **light sleep 에 한 번도 진입하지 못한 것**이었다:
    FREERTOS_HZ=100 → 1 tick = 10ms
    FREERTOS_IDLE_TIME_BEFORE_SLEEP=3 → 문턱 3 tick = **30ms**
    _btn_task 가 vTaskDelay(10ms)=**1 tick** 마다 깨워 유휴가 30ms 를 절대 못 넘음
    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
2026-08-14 fix(rf): PROG 긴 누름 무응답 — byte7 재전송 인덱스 복원 + 절전 PM 락 해제
    ■ PROG 긴 누름이 오래전부터 안 되던 진짜 원인
    _build_frame 이 byte7 을 전 프레임 0x84 로 고정하고 있었다. 정품(그리고
    ESPSomfy)은 재전송마다 올린다 — 첫 프레임 0x84, 재전송 196+rep*4.
    송신 루프에서 프레임마다 갱신하고, 체크섬이 byte7 을 입력으로 받으므로
    byte9 도 함께 재계산한다(조합 명령은 byte9 실측 고정값이라 제외).
    타이밍은 건드리지 않았다 — 과거 "byte7 가변 → 모터 무응답" 기록은 타이밍
    표준값과 묶어 바꾼 것이라 byte7 이 누명을 썼던 것으로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
    [app_main.cpp, cc1101.c, somfy_rts.c]
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2026-08-14 fix(diag): intdiag 가 LP 코어 폴링을 멈추도록 + PCF8575 데이터시트 대조 기록
    ■ intdiag 가 지금은 거짓 결과를 낸다 (수정)
    PCF8574/8575 의 `~INT` 는 **포트를 읽으면 해제**된다. ③(LP 코어)이 들어오면서
    LP 가 2ms 마다 PCF 를 읽으므로, HP 폴링만 멈추는 기존 intdiag 로는 INT 가 LOW 로
    유지되지 않는다 → 관찰 구간이 통째로 HIGH 로 보여 "선이 안 움직인다"는 잘못된
    결론이 나온다.
    → 관찰 전 `ulp_enabled = 0` 으로 LP 폴링을 멈추고 끝나면 복구한다.
    ※최초 측정(2026-08-13 13:46, 1bbcbc5)은 LP 코어 도입(18:54, f45ac86)보다 5시간
    앞서서 이 문제가 없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
    [button_handler.c]
2026-08-16 fix(h2/c6): 진단기록 보존 + H2 패닉·측정 정상화 + 보드 기본값 실기 일치
    ■ 방전 기록이 지워지던 진짜 원인 (재부팅마다 소멸)
    ① 부팅 첫 판독이 항상 "USB" 로 읽혔다. now_usb 는 2초 디바운스를 쓰는데
    첫 루프에서 usb_low_since_us 가 방금 now 로 채워져 경과 0 → 배터리인데도
    true. 그래서 이어받기를 안 부르고, 2초 뒤 뒤집히면 "USB 분리" 로 오인.
    ② 새 세션이 _batlog_reset() 으로 링을 통째로 비웠다. ①과 겹쳐 배터리로
    부팅할 때마다 과거 기록이 전부 사라졌다.
    → ① 배터리 부팅이면 디바운스 창을 지난 것으로 놓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
    [partitions.csv]
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2026-08-19 fix(c6): PROG 자동 송신 사고 — 폭주 차단 + LP 신선도 검사 + t_s 포화 해소
    ■ 사고: COM7 C6 를 하루 방치했더니 버튼이 전혀 안 먹고 **혼자서 PROG 를 계속 송신**
    PROG 는 모터를 프로그래밍 모드로 넣는 명령이라 블라인드 설정이 바뀔 위험이 있다.
    ■ NVS 방전 로그 실측 (logs/nvs_c6_stuck.bin 로 보존)
    이벤트 분포: PROG 281건 / 주기 18건 / 기타 1건 ← 링 300칸을 PROG 가 채움
    배터리 3,794~3,826mV (52~54%), 37.8시간 배터리 세션
    sleep% 43→75→63→54→52→76 (계속 변함)
    ★`sleep%`·`주기` 기록이 살아 움직였다 → "LP 정지로 공유 RAM 이 얼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
    [batlog_decode.py, button_handler.c]
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2026-08-19 fix(vibe): 한 번 두드려도 안 깨어남 — 평상시 LOW 를 "센서 고장"으로 오판
    사용자 신고: "두세번 두드려야 화면이 깨어난다"(H2·C6 둘 다).
    원인이 두 겹이었고, 둘 다 실기 기록으로 확정했다.
    ① **평상시(all-LOW)를 센서 고장으로 판정**하고 있었다 — 주원인.
    X160 은 평상시 **닫힘 = LOW** 인데 판정식이 `st_high == 0` 도 고장으로 봤다.
    가만히 두면 2초(200샘플)마다 고장으로 굳어 진동을 통째로 무시한다.
    로그가 그대로 남아 있었다(여러 세션에서 반복):
    [VIBE] 정상 복귀 (최근 200샘플 HIGH=1) — 진동 다시 인정
    [VIBE] 센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
    [button_handler.c]
2026-08-21 fix(bat): 잔량 0% 잠김 — 하한 조건부 해제 + 충전 천장 출발점 교정
    신고: COM7 C6 를 장시간 방치했더니 잔량·충전률이 0%. USB 를 다시 꽂아도
    0% 근처에서 거의 안 올라온다.
    NVS 방전기록(세션 #2, 300건/13.5시간)이 원인을 그대로 보여줬다.
    #0~39 4085 → 4068 mV 95%
    #40~59 4069 → 2651 mV 0% ← 급락
    #60~99 2129 mV 바닥 0%
    #100~299 2656 → 3845 mV 0% ← 8시간에 걸쳐 회복해도 0% 고정
    전압이 3845mV(약 60%)까지 돌아왔는데도 세션 내내 0% 였다.
    (A) **하한(s_pct_floor)이 단조 비증가라 한 번 0% 가 되면 못 풀린다.**
    원래 의도는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
    [bat_floor_release_sim.py]
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2026-08-22 fix(build): H2 링크 깨짐 — g_wake_iter 정의가 batlog 가드 안에 있었다 + H2 -Os
    ## 링크 에러
    undefined reference to `g_wake_iter' (somfy_app.c / oled_ui.c 여러 곳)
    깨어남 계측 카운터의 **정의**를 batlog 블록(`#if BOARD_BATLOG_ENABLE`) 안에
    뒀는데 H2 는 그 값이 0 이라 통째로 빠졌다. 카운터를 올리는 쪽
    (button_handler·oled_ui·메인 루프·hold_repeat)은 보드 설정과 무관하게 항상
    컴파일되므로 정의도 무조건 있어야 한다.
    → include 블록 끝(가드 밖)으로 옮겼다. NVS 로 남기는 쪽만 가드 안에 있으면 된다.
    ※C6 에서만 빌드해 못 잡았다. `BOARD_HAS_BAT_AD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
2026-08-24 fix(pm): H2 가 13.9시간 내내 안 잔 이유 — 8/15 `bt` 락 수정이 C6 오버레이에만 있었다
    ## 증상
    H2 배터리 13.9시간 실측: light sleep **0.0%**. 그런데 batlog 의 pm 열은 **3**
    (= light sleep ON + 배터리) — **esp_pm_configure 는 정상**이었다.
    같은 조건에서 C6 는 96.2% 잔다.
    ## 계측이 이름으로 찍어줬다 (sim/tools/pmdump_decode.py)
    esp_pm_dump_locks 는 stdout 으로만 출력하는데 H2 는 배터리 중 USB 콘솔이 죽고
    write 도 불안정하다 → open_memstream 으로 받아 NVS 에 남기게 했다.
    Name Type Active Total_count Time(%)
    bt APB_FREQ_MAX 1 1 100%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
2026-08-31 fix(btn): "PROG 가 가끔만 눌린다" — 접점이 아니라 우리가 막고 있었다
    실측(COM8): PROG 를 43회 눌러 **43회 전부 정상 검출**됐다(hold 42~203ms,
    사람 손의 자연스러운 편차). 그런데 10회만 송신되고 33회는 PROGGUARD 가 막았다.
    접점·PCF·LP 코어는 멀쩡했다. 배터리 구동 구간은 NVS batlog 로 확인 — 19초
    세션에 PROG 6회가 전부 기록돼 있었고 6번째부터 막혀 있었다.
    ★PROG 횟수 가드 제거. 막으려던 사고를 이 방식으로는 **원리상 잡을 수 없다**:
    LP 코어가 멈춰 PCF 값이 얼어붙으면 '눌린 채 유지'라 누름 이벤트는 1회만 난다.
    그 사고의 실제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
    [oled_ui.c, oled_ui.h]
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2026-09-01 fix(bat): "USB 뽑으니 배터리가 급속도로 준다" — 방전이 아니라 표시가 걸어내려간 것
    NVS 방전기록이 그대로 증명한다. USB 분리 직후 60초:
    t=0초 4004mV 95% ← 충전 중 표시값을 방전 세션이 물려받음
    t=20초 4004mV 91%
    t=40초 4004mV 87%
    t=60초 4002mV 83% ← 참값 도달, 여기서 멈춤
    전압은 2mV 밖에 안 떨어졌는데 표시만 95→83% 로 내려갔다. 하강 제한
    (BAT_DISP_MAX_DROP_PCT=1, 측정 5초)에 걸려 **1%씩 12번(60초)** 기어 내려간 것이다.
    5초마다 눈금이 하나씩 빠지니 사용자 눈에는 급감으로 보인다. 배터리는 멀쩡했다.
    bat_displ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
    [bat_display_rate_sim.py, oled_ui.c]
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2026-09-27 perf(pm): 배터리 5.2일 — 깨어남 339→32회/초, 범인은 CHG_STAT 레벨 웨이크였다
    실측 결과 (COM8, 완전 방전 2회)
    1차 125.2시간 = 5.2일 (4126mV 100% -> 3560mV 9.2%), 재부팅 0회
    2차 97.4시간 중간 재연결, 1차 종점까지 연장 시 약 123시간 — 2% 일치
    초당 절전 32.2회 / sleep 97.3% / 회당 깨어있음 0.84ms — 두 회차 1~2% 안 일치
    ━━ 핵심 수정: CHG_STAT 웨이크를 걸지 않는다 (BOARD_CHG_STAT_ACTIVE_HIGH 보드) ━━
    CHG_STAT(xiao-c6 IO17 / H2 GP12)은 VBUS 100k/150k 분압 노드이고 내부
    풀다운이 꺼져 있다(BOARD_CHG_STAT_EXT_PULLDOWN=1). USB 가 빠지면 상단 100k 가
    죽은 레일에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
2026-10-06 fix(dsleep): 깊은잠 대조군 첫 유효 측정 — 범인은 칩, 기판은 평소 소비의 5%
    판정 (COM7, 같은 셀·같은 전압대 4.04~4.12V, 연달아)
    깊은잠 12시간 4125 -> 4121mV -0.33 mV/h
    평소 동작 9시간 4102 -> 4044mV -6.47 mV/h (깨어난 뒤 배터리로 돈 구간)
    -> 약 20배. 기판 전체(OLED off, CC1101 SPWD, PCF, LDO, 분압, 충전 IC)는
    평소 소비의 약 5%(~0.3mA)다. 나머지 95% 는 칩 — 펌웨어로 공략 가능.
    OCV 표나 셀 용량 가정이 필요 없는 비교다(같은 전압대 mV/h 를 바로 나눔).
    이 측정을 성립시키려고 고친 것
    - OLED 를 끄고 잔다. SSD1306 은 ESP32 와 별개 칩이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
2026-10-12 perf(rf): 얕은잠마다 CC1101 CSn 이 떠서 SPWD 가 97% 무력화 — 5.2일 → 6.4일
    CC1101 의 SPWD(9/1, 83e0845)는 사실상 한 번도 제대로 작동하지 않았다.
    CONFIG_PM_SLP_DISABLE_GPIO=y 면 IDF 가 부팅 시 한 번 esp_sleep_config_gpio_isolate()
    로 **모든 GPIO** 의 절전 상태를 DISABLE + FLOATING 으로 정한다(sleep_gpio.c).
    그래서 얕은잠마다 CSn 이 풀 저항 없이 뜨고, LOW 쪽으로 흘러 칩을 깨워 IDLE
    (~1.7mA)로 남겼다. 그때는 CHG_STAT 폭주가 모든 측정을 덮어 아무도 몰랐다.
    증거 — 113.6시간 동시 A/B (같은 펌웨어, 스위치 하나)
    COM8 대조군 COM7 수정
    탐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
2026-10-21 fix(pm): GPT 재감사 N01·N03·N04·N06·N08·N09 반영 — 70.7시간 A/B 에서 COM8 대비 41% 덜 썼다
    4a62bdf 의 재감사(doc/POWER_SAVING_REAUDIT_2026-10-19.md) 대응. 모든 로직은 빌드 전에 sim/tools 시뮬로
    검증했고 C6·H2·BATLOG=0·배터리 회로 없는 구성 문법 검사를 통과했다. COM7 실기 확인(버튼 전부 정상 —
    사용자 확인), COM8 은 대조군으로 10/16 펌웨어 유지, H2 는 컴파일만.
    0. 직전 펌웨어(e9ed0b5)의 장시간 결과 — 70.7시간 동시 정지 대기, 둘 다 만충·재부팅 0
    · 성공 절전 COM7 3.2회/초(거부 0.7%) vs COM8 31.9회/초(거부 4.3%), 깨어있음 0.6% vs 1.7%
    · 소비 비율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
2026-10-28 perf(rf): 얕은잠 중 XIAO 안테나 핀을 놓는다 — 모듈 내부 바이어스 저항에 1.01mA 가 흐르고 있었다
    doc/HARDWARE_POWER_AUDIT_V6_2026-10-21.md §3 의 최우선 후보를 확인·수정·실측했다.
    원인
    XIAO ESP32C6 모듈 **안에** R21 10k(3.3V→GPIO3 풀업)와 R24 5.1k(GPIO14→GND 풀다운)가 있다
    (Seeed v1.0 회로도 5쪽, R22·R23 미실장). 외장 안테나를 쓰려고 GPIO3 LOW(스위치 전원 ON)·GPIO14 HIGH
    (외장 선택)로 구동하는 동안 3.3/10k + 3.3/5.1k = 0.98mA 가 저항으로 그냥 흐른다.
    9/02 부터 gpio_sleep_sel_dis 로 이 두 핀을 얕은잠 중에도 구동해 왔다. 근거는 "SED 는 자면서 폴링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
2026-10-28 fix(batlog): 끝난 방전 세션을 배터리 재부팅이 이어받던 버그 — 6일 A/B 의 COM7 기록이 틀렸다
    실기(10/23~29 COM7): 10/22 에 USB 를 꽂아 세션 #70 이 끝났는데, 10/23 분리 순간 배터리 재부팅이 나자
    #70 을 이어받았다. batlog 기준점이 10/22 값(4094mV/98%)이 됐고 경과가 그 뒤로 이어 붙었다.
    원인: USB 연결 분기는 저장(_batlog_flush_if_due) **뒤에** s_dis_t0_us = 0 을 해서 NVS dis_on 이 1 로 남았다
    (그 뒤로는 dirty 가 없어 다시 저장되지 않는다). _batlog_try_resume 은 "배터리 부팅 + dis_on=1" 이면 이어받는다.
    수정 (_batlog_close_session)
    · 세션이 끝나면(배터리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
2026-10-31 perf(rot): 쉬는 로터리의 닫힌 접점 핀을 LP 가 LOW 로 주차한다 · lsfloor 정착 표시·안테나 고정 수정 · 10/29 남은 항목
    10/31 — 로터리 주차 (main/lp_core)
    - 하프스텝 로터리가 00(두 접점 닫힘)에 멈추면 PCF8575 의 약한 전류원(핀당 30~300uA)이 접점으로 계속 흐른다
    (10/30 lsfloor rot: 0.13+-0.36mA, 접점당 66uA). LP 가 로터리 비트가 200ms 그대로일 때만 LOW 로 읽힌 핀을
    PCF 출력 0 으로 몰고, 다음 폴은 0xFFFF 쓰기 + 반복 START 읽기(한 트랜잭션)로 놓고 읽는다.
    - parked 초깃값 = 두 핀 다(LP 재적재 때 래치를 모른다), LP->HP 인계 때 0xFFFF 쓰기.
    - 시뮬 ro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

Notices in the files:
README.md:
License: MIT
